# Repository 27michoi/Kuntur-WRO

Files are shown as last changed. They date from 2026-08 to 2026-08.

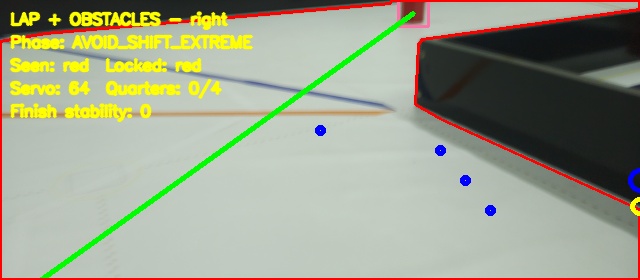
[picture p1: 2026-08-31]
step13_lap_results/frames/right_20260828_172251/frame_0032_AVOID_SHIFT_EXTREME.jpg

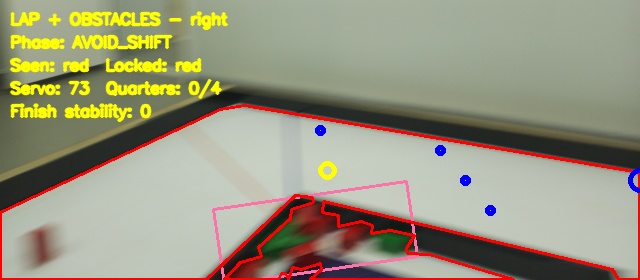
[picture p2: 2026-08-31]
step13_lap_results/frames/right_20260828_172251/frame_0070_AVOID_SHIFT.jpg

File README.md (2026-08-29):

## Introducción

Nuestro equipo Kuntur creó «Luna» para participar en el Campeonato Nacional de la WRO 2026 (Lima, Perú). «Luna» es un carro de conducción autónoma, diseñado para detectar obstáculos y analizar su entorno con el fin de adaptar su conducción de forma adecuada. Colocamos la Raspberry Pi 3 Wide en la parte superior del carro. Utilizamos un stepper motor para crear un sistema de diferencial que acciona las dos ruedas traseras y un servomotor para crear un eje para las dos ruedas delanteras. Programamos nuestra cámara para que detectara líneas específicas, objetos de colores distintivos y las paredes.

**Por favor, lee los archivos README.md en cada carpeta para comprender mejor nuestra documentación.**

---

### Visión General y Filosofía del Proyecto

El desarrollo de «Luna» representa la culminación de un proceso intensivo de ingeniería mecatrónica, diseño de software y resolución de problemas por parte del Equipo Kuntur. Diseñar un vehículo verdaderamente autónomo capaz de desenvolverse de manera fluida y precisa dentro de un tapete delimitado de 3x3 metros exige una integración armónica entre el hardware mecatrónico y los algoritmos de decisión en tiempo real.

La navegación en un espacio acotado presenta desafíos únicos. El espacio limitado requiere que las maniobras de esquiva, corrección de trayectoria y detección de límites se ejecuten con una latencia mínima. A diferencia de plataformas más grandes o que operan en entornos abiertos, «Luna» no cuenta con margen de error para desviaciones acumulativas. Una pequeña imprecisión en la lectura de la línea de carril o un retardo en la señal del servo puede traducirse en una colisión contra una pared o la desalineación irreversible del vehículo dentro del circuito. Por esta razón, el Equipo Kuntur adoptó un enfoque metodológico estricto: cada decisión de diseño, desde la selección de materiales hasta la estructura de las clases en el código fuente, se orientó hacia la estabilidad, la repetibilidad y el control de precisión.

El nombre «Luna» simboliza la exploración y la guía en entornos desafiantes, reflejando el espíritu competitivo y la dedicación del equipo durante las etapas de conceptualización, prototipado y pruebas finales para el Campeonato Nacional de la WRO 2026.

---

### Arquitectura de Hardware y Diseño Mecánico

El chasis de «Luna» se diseñó bajo el principio de rigidez estructural y modularidad. Para lograr un vehículo liviano pero resistente a las variaciones dinámicas de masa durante la aceleración y el viraje, combinamos componentes fabricados mediante impresión 3D en PLA con elementos estructurales de LEGO Technic.

#### Chasis Híbrido y Modularidad

La base estructural del carro se divide en tres secciones claramente diferenciadas:

1. **Módulo Delantero de Dirección:** Alberga el servomotor y el varillaje mecánico que conecta los manguetones de las ruedas delanteras. Se diseñó específicamente para permitir un ajuste de alineación rápido y garantizar que el eje de rotación de cada rueda respete la geometría de giro sin generar tensiones en los brazos mecánicos.
2. **Cuna Central de Electrónica:** Posicionada estratégicamente en el centro de gravedad del vehículo. En esta zona se fijan la Raspberry Pi 3 Wide, el microcontrolador de bajo nivel, los convertidores de voltaje y los circuitos de distribución de energía. Al concentrar el peso electrónico en el centro, se reduce el momento de inercia del vehículo, permitiendo giros más ágiles y predecibles.
3. **Módulo Trasero de Propulsión:** Contiene el motor paso a paso (stepper motor), el tren de engranajes reductor y el mecanismo diferencial que transmite el movimiento a las ruedas traseras.

La integración de piezas de LEGO Technic en las vigas longitudinales permitió iterar con rapidez la posición exacta de los componentes durante las fases iniciales de prueba. Posteriormente, los soportes definitivos para la cámara, los sensores y las placas electrónicas se modelaron en CAD y se imprimieron en 3D, garantizando un acoplamiento perfecto mediante tornillería estandarizada. Los archivos de estos diseños están disponibles en la carpeta `models`.

#### Sistema de Tracción Posterior por Motor Paso a Paso Único

Una de las decisiones técnicas más representativas en el diseño de «Luna» fue la utilización de un único motor paso a paso para mover ambas ruedas traseras. En lugar de recurrir a la clásica configuración de dos motores de corriente continua independientes con control diferencial por software, optamos por un esquema mecánico basado en un diferencial físico impulsado por el motor paso a paso.

Esta configuración ofrece ventajas decisivas:

* **Control de Odometría Absoluta:** Un motor paso a paso avanza en incrementos angulares exactos y discretos. Al conocer la relación de transmisión de los engranajes y el radio de las ruedas, el software puede determinar con extrema precisión la distancia lineal recorrida contando simplemente la cantidad de pulsos enviados al motor. Esto elimina la necesidad de instalar codificadores ópticos o magnéticos externos en los ejes de las ruedas.
* **Eliminación de Desviaciones por Diferencia de Motores:** En sistemas con dos motores de corriente continua, pequeñas variaciones en la resistencia interna de los motores o en la fricción de los rodamientos causan que una rueda gire ligeramente más rápido que la otra, desviando al vehículo de su trayectoria recta. Al usar un solo motor paso a paso unido a un diferencial mecánico, ambas ruedas reciben la misma fuerza motriz, garantizando un avance perfectamente rectilíneo cuando la dirección se mantiene en el centro.
* **Diferencial Mecánico Activo:** Al tomar curvas cerradas dentro del tapete de 3x3 metros, la rueda trasera interior recorre una distancia menor que la rueda exterior. El diferencial mecánico permite esta diferencia de velocidad angular entre las ruedas sin perder la tracción del motor, evitando que los neumáticos derrapen o arrastren sobre la superficie del tapete.

#### Sistema de Dirección Delantera

La dirección de «Luna» se confía a un servomotor de alta precisión conectado a las ruedas delanteras mediante un varillaje articulado.

* **Geometría de Dirección:** El mecanismo se diseñó para aproximar la geometría de giro Ackermann, asegurando que la rueda interior mantenga un ángulo ligeramente superior a la rueda exterior durante un viraje. Esto reduce la fricción lateral del neumático delantero y proporciona un control de trayectoria suave.
* **Calibración y Protección Mecánica:** A través de rutinas de calibración específicas, fijamos el ángulo de centro mecánico en el software y definimos bordes de seguridad rígidos. Estos límites previenen que el servomotor intente girar más allá del tope físico de la suspensión, evitando sobrecalentamientos, consumo excesivo de batería o daños en los engranajes del servo.

---

### Esquema Electrónico y Distribución de Alimentación

El correcto diseño del sistema eléctrico es crucial para prevenir fallas aleatorias, caídas de voltaje o ruido electromagnético que pueda interferir con el procesamiento de la Raspberry Pi o la lectura de señales. Los esquemas electromecánicos completos se encuentran en la carpeta `schemes`.

#### Sistema de Procesamiento Jerárquico

Para optimizar el rendimiento y garantizar tiempos de respuesta en tiempo real, dividimos las tareas computacionales en dos niveles jerárquicos:

* **Procesador de Alto Nivel (Raspberry Pi 3 Wide):** Actúa como el "cerebro" del robot. Ejecuta el sistema operativo Linux, la pila de visión por computador en Python mediante la librería OpenCV, la lógica de navegación general, la detección de colores y obstáculos, y la toma de decisiones tácticas.
* **Controlador de Bajo Nivel (Microcontrolador Arduino):** Actúa como el "sistema nervioso" del robot. Se encarga exclusivamente de generar las señales físicas en tiempo real: los pulsos de alta frecuencia para el driver del motor paso a paso y la señal de modulación por ancho de pulsos (PWM) para el servomotor de la dirección.

Esta separación garantiza que las tareas críticas de tiempo como la generación de pasos del motor no sufran interrupciones ni fluctuaciones debido a la carga de procesamiento de la cámara en la Raspberry Pi.

#### Red de Alimentación y Aislamiento Electrónico

El sistema eléctrico de «Luna» se alimentó mediante un esquema de distribución cuidadosamente aislado:

* **Línea de Potencia (Motores y Servo):** Alimenta los actuadores mecánicos a través de un controlador dedicado (driver) para el motor paso a paso y una línea de regulador de voltaje de alta corriente para el servomotor. Esto aísla los picos de corriente que ocurren durante los arranques o detenciones bruscas del motor.
* **Línea de Lógica (Raspberry Pi y Sensores):** Cuenta con una regulación de voltaje filtrada que proporciona un suministro de energía limpio a la Raspberry Pi 3 Wide y al microcontrolador.
* **Masa Común y Filtrado:** Todas las líneas de masa del sistema se unieron en un punto común para establecer una referencia de voltaje idéntica en toda la electrónica. Se incorporaron condensadores de desacoplo de gran capacidad cerca de los controladores de motor para absorber los transitorios de inductancia.

---

### Sistema de Visión por Computador y Navegación Autónomica

El único sensor primario de percepción del entorno en «Luna» es la cámara Raspberry Pi 3 Wide colocada en la parte superior del chasis. Elegimos una lente de gran angular para maximizar el campo de visión, permitiendo que el robot observe simultáneamente el suelo inmediatamente delante de su paragolpes y las paredes o límites laterales del tapete.

#### Procesamiento de Imágenes en el Espacio de Color HSV

Las variaciones en la iluminación ambiental dentro del recinto de la competencia pueden alterar severamente la percepción del color si se trabaja en el espacio RGB convencional. Por ello, la primera etapa de nuestra canalización de visión convierte los fotogramas capturados por la cámara al espacio de color HSV (Hue, Saturation, Value):

1. **Canal Tono (Hue):** Representa el color puro de manera independiente de la intensidad luminosa. Esto permite definir rangos de umbración estables para aislar colores clave como el rojo, el verde, el azul y el negro de las líneas o paredes.
2. **Canales Saturación (Saturation) y Valor (Value):** Se utilizan para filtrar reflejos del suelo o zonas de sombra demasiado oscuras, asegurando que solo se procesen regiones con suficiente pureza de color.

#### Algoritmo de Detección de Paredes y Centrado de Carril

Para mantener a «Luna» en el centro del carril dentro del tapete de 3x3 metros, implementamos un algoritmo de análisis de contornos en la Región de Interés (ROI) de la imagen:

* **Definición de ROI:** Se descarta la parte superior de la imagen (que contiene elementos del entorno fuera del tapete) y se enfoca el procesamiento en la franja central e inferior del fotograma.
* **Segmentación de Límites:** Se aplican filtros morfológicos de erosión y dilatación para eliminar el ruido puntual. A continuación, se extraen los contornos de las paredes o líneas delimitadoras izquierda y derecha.
* **Cálculo del Punto Medio:** El software calcula el centroide espacial de los contornos detectados a ambos lados. La diferencia entre el centroide combinado de la pista y el centro geométrico del fotograma genera un vector de error. Este vector de error se convierte directamente en el ángulo de corrección para el servomotor de la dirección mediante una función de transferencia proporcional.

#### Detección y Evitación de Obstáculos

Además de seguir las paredes y líneas del circuito, «Luna» debe ser capaz de reaccionar ante obstáculos colocados en su trayectoria:

* **Evaluación de Área y Distancia:** Cuando el módulo de visión detecta una masa de color correspondiente a un objeto dentro de la ROI, calcula el área en píxeles del contorno. Si el área supera un umbral predefinido, el sistema determina que el objeto está a una distancia crítica de colisión.
* **Lógica de Esquiva por Código de Color:** Dependiendo del color del objeto identificado (por ejemplo, verde para esquivar por un costado o rojo para el lado opuesto), el algoritmo de decisión invalida temporalmente la referencia de centrado de paredes e introduce un desvío angular forzado en la dirección. Una vez que el contorno del objeto sale del campo de visión lateral de la cámara, el sistema retorna suavemente al modo de seguimiento de carril.

---

### Estructura del Software y Flujo de Control (`src`)

Todo el software desarrollado para controlar a «Luna» se encuentra documentado y estructurado modularmente dentro de la carpeta `src`. La arquitectura sigue patrones de diseño orientados a objetos en Python, asegurando un código limpio, reutilizable y fácil de depurar.

#### Arquitectura de Clases

* `run.py`: Script de entrada principal. Inicializa las clases de comunicación, la captura de video en un hilo dedicado, procesa el bucle principal de control y gestiona las paradas de emergencia.
* `classes/arduino_comms.py`: Encargada de gestionar la conexión serie (`/dev/ttyACM0` a 115200 baudios). Incluye funciones para empaquetar y enviar comandos de movimiento y leer las respuestas enviadas por el Arduino.
* `classes/image_algorithms.py`: Contiene los métodos matemáticos de visión por computador, la segmentación HSV, la detección de contornos, el cálculo de centroides y la generación de órdenes angulares.
* `battery.py`: Script de diagnóstico que evalúa la tensión del sistema antes de cada sesión de pruebas.

#### Protocolo de Comunicación Serie y Trama de Datos

La comunicación entre la Raspberry Pi y el Arduino se rige por un protocolo ligero basado en cadenas ASCII:

* **Comandos de Dirección y Velocidad:** Formateados como `m<ángulo>,<velocidad>.` (por ejemplo, `m85,1000.` indica fijar el servo en el centro de 85 grados y mover el motor paso a paso a 1000 pasos por segundo).
* **Comandos de Odometría Objetivo:** Formateados como `<pasos>!` (por ejemplo, `5000!` le indica al microcontrolador que debe avanzar exactamente 5000 pasos y detenerse).
* **Señales de Confirmación:** Cuando el microcontrolador completa una orden de pasos objetivo, transmite el carácter `'F'` por el puerto serie. La clase `ArduinoComms` intercepta este carácter para notificar al software principal que la maniobra ha concluido con éxito.

---

### Metodología de Calibración y Procedimiento Paso a Paso

Para garantizar que el vehículo funcione de forma idéntica en cada ejecución, establecimos un protocolo de calibración estructurado en 6 pasos que debe ejecutarse secuencialmente antes de cada competición o sesión de pruebas dinámicas.

```
+-----------------------------------------------------------------------+
|  Paso 1: Diagnóstico Electrónico y Nivel de Carga (battery.py)         |
+-----------------------------------+-----------------------------------+
                                    |
                                    v
+-----------------------------------------------------------------------+
|  Paso 2: Verificación de la Interfaz Serie (ArduinoComms)             |
+-----------------------------------+-----------------------------------+
                                    |
                                    v
+-----------------------------------------------------------------------+
|  Paso 3: Calibración de la Cámara y Umbralización HSV                 |
+-----------------------------------+-----------------------------------+
                                    |
                                    v
+-----------------------------------------------------------------------+
|  Paso 4: Calibración de Centro de Servo y Límites de Seguridad        |
+-----------------------------------+-----------------------------------+
                                    |
                                    v
+-----------------------------------------------------------------------+
|  Paso 5: Prueba de Avance / Parada Objetivo con Ruedas Elevadas       |
+-----------------------------------+-----------------------------------+
                                    |
                                    v
+-----------------------------------------------------------------------+
|  Paso 6: Pruebas Dinámicas en Pista y Ajuste de Bucle Cerrado         |
+-----------------------------------------------------------------------+

```

#### Paso 1: Diagnóstico Electrónico y Nivel de Carga

Antes de activar los motores, se ejecuta el script de diagnóstico de batería. Esto confirma que el voltaje de las líneas de lógica y potencia se encuentre dentro del rango nominal, evitando que caídas de tensión provoquen comportamientos anómalos en el motor paso a paso o en el procesamiento de la imagen.

#### Paso 2: Verificación de la Interfaz Serie

Se valida que el puerto USB serie entre la Raspberry Pi y el Arduino se abra correctamente a 115200 baudios, enviando tramas de prueba para medir la latencia del canal de comunicación y confirmar que no existan paquetes corruptos en el búfer.

#### Paso 3: Calibración de la Cámara y Umbralización HSV

Dado que la luz ambiente del recinto de la competición varía según la hora y la iluminación de la sala, colocamos al robot en diferentes puntos del tapete para ajustar los valores mínimos y máximos de los canales HSV. Guardamos estos parámetros en los archivos de configuración para garantizar una segmentación de color precisa.

#### Paso 4: Calibración de Centro de Servo y Límites de Seguridad

Se eleva el eje delantero para eliminar la fricción con el suelo. Mediante una consola interactiva, ajustamos el valor de `ANGLE_STRAIGHT` hasta que las ruedas delanteras queden perfectamente alineadas con el chasis (fijado nominalmente en 85 grados). Posteriormente, probamos los giros máximos a izquierda y derecha para establecer límites estrictos en el software que prevengan bloqueos mecánicos.

#### Paso 5: Prueba de Avance y Parada Objetivo con Ruedas Elevadas

Con el vehículo aún suspendido sobre un soporte, probamos el sistema de tracción posterior:

1. **Verificación de Dirección de Marcha:** Confirmamos que los comandos de velocidad positiva hagan girar ambas ruedas traseras en sentido de avance hacia adelante a través del diferencial.
2. **Respuesta a la Parada Objetivo:** Enviamos un comando de 5000 pasos y verificamos que el motor paso a paso se detenga automáticamente al alcanzar la cuenta exacta, transmitiendo la señal de confirmación `'F'` de regreso a la Raspberry Pi.

#### Paso 6: Pruebas Dinámicas en Pista y Ajuste de Bucle Cerrado

Finalmente, colocamos a «Luna» sobre el tapete de 3x3 metros. Ejecutamos el bucle de control completo en `run.py`, ajustando las ganancias de respuesta del algoritmo de dirección para lograr un seguimiento de carril fluido, sin sobreoscilaciones en las curvas y con una esquiva de obstáculos limpia y predecible.

---

### Organización de Repositorio y Documentación

Para garantizar que cualquier miembro de la comunidad de la WRO o jurado de la competencia pueda revisar, replicar o continuar nuestro trabajo, organizamos el repositorio oficial del Equipo Kuntur respetando una estructura estricta de carpetas. Cada directorio cuenta con su respectivo archivo `README.md` explicativo:

* **`t-photos/`**: Contiene la documentación fotográfica del equipo Kuntur. Incluye una foto oficial para la presentación de la competencia y una foto informal que refleja el espíritu colaborativo del grupo.
* **`v-photos/`**: Agrupa 6 fotografías detalladas de «Luna» desde todos los ángulos clave: vista superior (mostrando la disposición de la Raspberry Pi y el cableado), vista inferior (revelando el tren de engranajes del diferencial y el soporte del motor paso a paso), así como vistas frontal, posterior y laterales.
* **`video/`**: Contiene el archivo `video.md`, el cual proporciona el enlace directo al video demostrativo alojado en línea, donde se aprecia a «Luna» ejecutando una prueba completa de conducción autónoma en el tapete de 3x3 metros.
* **`schemes/`**: Alberga los esquemas mecánicos y electrónicos en formato JPEG, detallando la interconexión entre la Raspberry Pi, el Arduino, el driver del stepper motor, el servomotor y la red de alimentación.
* **`src/`**: Guarda la totalidad del código fuente ejecutable, incluyendo las clases de comunicación, los algoritmos de visión, los scripts de prueba individuales y el ejecutable principal `run.py`.
* **`models/`**: Contiene los archivos CAD en formato STL y código G para la impresión 3D de los componentes del chasis y soportes de sensores.
* **`other/`**: Reúne documentación complementaria, como hojas de datos técnicas de los componentes utilizados, bitácoras de pruebas de campo y archivos de configuración auxiliares.

---

### Resultados, Conclusiones y Agradecimientos

El desarrollo de «Luna» ha sido una experiencia de aprendizaje técnico inestimable para todo el Equipo Kuntur. A través de este proyecto logramos validar de manera práctica conceptos avanzados de mecatrónica, ingeniería de software, visión por computador y control en tiempo real.

El uso de un motor paso a paso acoplado a un diferencial mecánico demostró ser una alternativa innovadora y altamente eficiente para la tracción trasera de vehículos autónomos a pequeña escala, ofreciendo una odometría exacta sin incrementar la complejidad de sensores en el chasis. Del mismo modo, la arquitectura de procesamiento dual entre la Raspberry Pi 3 Wide y el Arduino garantizó un equilibrio perfecto entre capacidad de cómputo visual y precisión en la generación de señales de control.

Agradecemos sinceramente al Campeonato Nacional de la WRO 2026 en Lima, Perú, por brindar la oportunidad de poner a prueba nuestras capacidades de ingeniería, así como a nuestros mentores y familias por su apoyo constante durante las largas jornadas de diseño, impresión 3D y programación. Invitamos a todos los visitantes de nuestro sitio web a explorar las diferentes carpetas de nuestro repositorio para conocer a fondo los detalles técnicos que hacen de «Luna» un vehículo autónomo único.

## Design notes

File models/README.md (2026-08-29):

# 3D Models
____

## Resumen

Este directorio contiene los archivos STL de los componentes impresos en 3D de nuestro robot para la WRO 2026. Los modelos incluyen las piezas del chasis estructural, del mecanismo de dirección, de los soportes de los motores, del soporte de la cámara y otros componentes mecánicos utilizados en el vehículo.
También se incluye una descripción del armado del robot junto con indicaciones para el ensamblaje.

____

## Estructura del chasis

### Placas de base

[`BasePlaqueV4.stl`](./BasePlaqueV4.stl)
[`BasePlaqueV4-modifiedV1.stl`](./BasePlaqueV4-modifiedV1.stl) 

### Placas del medio

[`MiddlePlaqueV4.stl`](./MiddlePlaqueV4.stl)
[`MiddlePlaqueV4-modified_lu.stl`](./MiddlePlaqueV4-modified_lu.stl)

### Placas superiores

[`TopPlaqueV4.stl`](./TopPlaqueV4.stl)

____

## Sistema de conducción

### Componentes de dirección

[`DirectionRods3.stl`](./DirectionRods3.stl)
[`DirectionRodsShort3.stl`](./DirectionRodsShort3.stl)
[`DirectionTabsLH.stl`](./DirectionTabsLH.stl)
[`DirectionTabsRH.stl`](./DirectionTabsRH.stl)

### Componentes de servo

[`ServoHolderV2.stl`](./ServoHolderV2.stl)
[`ServoCover.stl`](./ServoCover.stl)

____

## Sistema de manejo

[`StepMotorBracker.stl`](./StepMotorBracket.stl)
[`BaseMotorBig.stl`](./BaseMotorBig.stl)
[`CouplingV3.stl`](./CouplingV3.stl)

____

## Sistema de cámara

[`CamHolderV4.stl`](./CamHolderV4.stl)

____

## Componentes externos y auxiliares

[`FrontWingV2.stl`](./FrontWingV2.stl)
[`ButtonHolder.stl`](./ButtonHolder.stl)

___

# Diseño Mecánico

## Descripción general

Esta carpeta contiene los archivos correspondientes al diseño mecánico del robot autónomo desarrollado para la competencia WRO Future Engineers.

El diseño mecánico tuvo como objetivo principal desarrollar una estructura resistente, modular y fácil de ensamblar, permitiendo realizar modificaciones rápidas durante la etapa de pruebas y preparación para la competencia.

Los principales criterios de diseño fueron:

- Lograr una estructura rígida y estable para soportar todos los componentes mecánicos y electrónicos.
- Permitir un montaje y desmontaje sencillo de las piezas.
- Facilitar el mantenimiento y reemplazo de componentes durante las pruebas.
- Mejorar la precisión del sistema de dirección y transmisión.

Las piezas personalizadas fueron diseñadas mediante software CAD y fabricadas mediante impresión 3D.

---

# Arquitectura del chasis

El robot está compuesto por una estructura modular de tres niveles principales:

1. Placa inferior del chasis.
2. Placa intermedia para componentes electrónicos.
3. Placa superior para Raspberry Pi y sistema de cámara.

Las placas están unidas mediante pernos y separadores previamente calculados, permitiendo mantener una distancia adecuada entre niveles para organizar los componentes internos y evitar interferencias mecánicas.

---

# Placa inferior del chasis

La placa inferior constituye la base principal del robot.

En esta sección se encuentran instalados:

- Cuatro ruedas alineadas.
- Sistema de transmisión mediante motor paso a paso.
- Sistema diferencial de engranajes.
- Sistema de dirección Ackermann.
- Servomotor de dirección.
- Soporte para convertidor de voltaje DC-DC.

El diseño fue desarrollado para mantener una distribución equilibrada de peso y garantizar estabilidad durante el movimiento autónomo.

---

# Sistema de transmisión

## Motor y diferencial

El sistema de movimiento utiliza:

- Motor paso a paso NEMA 17.
- Engranaje diferencial bevel de 28 dientes.
- Eje de transmisión hacia las ruedas posteriores.

El motor transmite el movimiento mediante el sistema diferencial, permitiendo que las ruedas puedan adaptarse a diferentes velocidades durante los giros.

Este mecanismo reduce esfuerzos mecánicos y mejora la estabilidad del vehículo en curvas.

El soporte del motor fue diseñado para mantener una correcta alineación entre los engranajes y evitar pérdidas por desajustes mecánicos.

---

# Sistema de dirección Ackermann

El robot utiliza una geometría Ackermann para mejorar el comportamiento durante los giros.

El sistema está compuesto por:

- Soportes de ruedas delanteras.
- Elementos de unión de dirección.
- Ejes de giro.
- Servomotor.
- Sistema de conexión mecánica.

Durante las primeras pruebas se identificó que las piezas impresas en 3D presentaban cierta resistencia debido al contacto directo entre superficies plásticas.

Esto generaba:

- Mayor fricción.
- Menor precisión del movimiento.
- Mayor esfuerzo del servomotor.
- Variaciones en el ángulo de giro.

Para solucionar este problema se rediseñaron los soportes incorporando rodamientos de acero en los puntos de rotación.

La implementación de rodamientos permitió:

- Reducir la resistencia mecánica.
- Mejorar la suavidad del movimiento.
- Aumentar la precisión del control del servomotor.
- Obtener una respuesta más estable del sistema Ackermann.

---

# Placa intermedia de componentes electrónicos

La placa intermedia fue diseñada para organizar y proteger los componentes eléctricos del robot.

En ella se montan:

- Arduino Uno R3 Microcontroller.
- Mini protoboard.
- Baterías recicladas 18650 (4 celdas).
- Convertidor DC-DC de 12V a 5V (6A - 30W).
- Distribución del cableado.

La separación entre la placa inferior y la placa intermedia fue definida mediante separadores, considerando:

- Espacio necesario para cables.
- Facilidad de mantenimiento.
- Protección de componentes.
- Evitar contacto entre sistemas mecánicos y eléctricos.

---

# Sistema de alimentación

El robot utiliza un conjunto de cuatro baterías recicladas 18650.

La ubicación del sistema de baterías fue definida buscando:

- Mantener el centro de gravedad equilibrado.
- Evitar desplazamientos de peso durante aceleraciones.
- Mejorar la estabilidad del vehículo.

El convertidor DC-DC permite adaptar la tensión del sistema de baterías a los niveles requeridos por los componentes electrónicos.

---

# Placa superior y sistema de visión

La placa superior permite cerrar la estructura del robot y proporciona soporte para:

- Raspberry Pi 5 Starter Kit.
- Cámara Raspberry Pi.

El soporte de cámara fue diseñado para mantener una posición fija respecto al chasis.

Su ubicación permite realizar una correcta calibración considerando:

- Distancia hacia obstáculos.
- Altura de visión.
- Reconocimiento de elementos de la pista.

Una posición estable de la cámara permite mejorar la repetibilidad del sistema autónomo durante las pruebas.

---

# Procedimiento de ensamblaje

## 1. Ensamblaje del chasis inferior

1. Instalar el motor NEMA 17 en su soporte.
2. Colocar el sistema diferencial de engranajes.
3. Verificar alineación del eje de transmisión.
4. Instalar las ruedas posteriores.
5. Montar el sistema Ackermann delantero.
6. Instalar los rodamientos en los puntos de giro.
7. Conectar el servomotor al sistema de dirección.

---

## 2. Instalación de placa intermedia

1. Colocar los separadores entre placas.
2. Fijar la placa intermedia mediante pernos.
3. Instalar Arduino Uno.
4. Colocar baterías y convertidor DC-DC.
5. Organizar conexiones eléctricas.

---

## 3. Instalación de placa superior

1. Fijar la placa superior al conjunto.
2. Instalar Raspberry Pi 5.
3. Colocar soporte de cámara.
4. Ajustar posición de cámara según las necesidades de calibración.

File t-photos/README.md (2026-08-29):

## Fotos del equipo

Este directorio contiene dos fotos del equipo (una oficial y otra divertida en la que aparecen todos los miembros del equipo).

Aunque nuestros nombres son Camilla, Luciana y Minjun (izquierda a derecha en las fotos), nuestras identidades en la foto divertida son Raspi, Arduino y protoboard!

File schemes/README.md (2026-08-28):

Electromechanical diagrams
====

___

## Introducción

Este directorio documenta la configuración electromecánica de nuestro vehículo. Los esquemas ilustran cómo se conectan entre sí, dentro del robot, la Raspberry Pi, el Arduino, los motores, el controlador de motores y otros componentes auxiliares.

Nuestro sistema divide las responsabilidades entre dos controladores principales. La Raspberry Pi 5 actúa como nuestra computadora principal, procesando la información procedente del módulo de cámara Raspberry Pi Camera Module 3 Wide y ejecutando las pruebas integradas que se utilizan para evaluar el rendimiento general del robot. El Arduino Uno se encarga de los mecanismos de movimiento del vehículo, comunicándose con los sistemas de dirección y conducción.

Los diagramas representan tanto la configuración completa del vehículo como una configuración de prueba centrada en el chasis.

____

## Configuración del Sistema

El sistema electromecánico de nuestro robot puede entenderse a través de cuatro funciones principales.

1. **Visión y cálculo**: a cargo de la Raspberry Pi 5 y el módulo de cámara Raspberry Pi 3 Wide.
2. **Dirección**: controlada mediante el Arduino, el servomotor y el mecanismo de dirección de las ruedas delanteras.
3. **Propulsión**: controlada mediante el Arduino, el controlador del stepper motor driver y el stepper motor.
4. **Poder**:  cuatro baterías de 3,7 V y canalizada a través del sistema de gestión de energía del vehículo.

La separación de estas funciones permite que la Raspberry Pi se centre en el procesamiento de las imágenes de la cámara y en las pruebas de nivel superior, mientras que el Arduino gestiona el hardware responsable del movimiento físico del vehículo.

____

## Configuración Completa del Vehículo

### Raspberry Pi 5 y Cámara

La Raspberry Pi 5 actúa como ordenador principal del robot, procesando los datos que recibe del módulo de cámara Raspberry Pi Camera Module 3 Wide y ejecutando nuestras pruebas de sistema completo. La cámara wide ofrece una visión más amplia del entorno de la competición.

### Arduino Uno

El Arduino Uno actúa como controlador de movimiento del vehículo, comunicándose con los sistemas de dirección y movimiento, mientras que la Raspberry Pi se encarga de la visión y del procesamiento de nivel superior.

### Servomotor (+ruedas delanteras)

El servomotor ajusta el ángulo de las ruedas delanteras para controlar la dirección del robot. La estructura de las ruedas delanteras se basa en la geometría de dirección de Ackermann.

### Stepper motor y stepper motor driver

El controlador del stepper motor driver recibe señales de control del Arduino y acciona el stepper motor, que impulsa el movimiento de las ruedas traseras del robot.

### Mini protoboard

La mini protoboard centraliza las conexiones eléctricas en un espacio compacto, lo que ayuda a mantener un esquema de cableado organizado dentro de las limitaciones de tamaño del vehículo.

### Sistema de power

El robot se alimenta mediante cuatro baterías de 3,7 V, conectadas a través de un interruptor de on/off y un convertidor DC-DC para distribuir la potencia adecuada a los componentes electrónicos.

___

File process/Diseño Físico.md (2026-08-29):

# Diario de Ingeniería - Diseño Físico del Robot Autónomo

## Inicio del proceso de diseño

El desarrollo mecánico del robot inició mediante el análisis de diferentes diseños utilizados en competencias anteriores de WRO Future Engineers, sistemas motrices encontrados en vehículos comerciales y soluciones mecánicas disponibles en plataformas como LEGO.

El objetivo inicial fue tener una arquitectura que facilitara:

- El montaje y desmontaje durante las pruebas.
- La modificación rápida de componentes.
- La accesibilidad de los sistemas internos.
- La preparación del robot para la presentación final.

Luego de evaluar diferentes alternativas, se decidió implementar una estructura modular basada en un chasis de tres niveles.

---

# Decisión del diseño modular del chasis

## Problema identificado

Un diseño de una sola placa generaba dificultades para integrar:

- Sistema de transmisión.
- Dirección.
- Baterías.
- Placas electrónicas.
- Sistema de procesamiento Raspberry Pi.
- Cámara.

Además, dificultaba realizar modificaciones rápidas durante las pruebas.

## Solución implementada

Se desarrolló un diseño compuesto por tres niveles:

### Nivel inferior:
Sistema mecánico:

- Motor.
- Diferencial.
- Ruedas.
- Dirección Ackermann.

### Nivel intermedio:
Sistema electrónico:

- Arduino.
- Baterías.
- Cableado.
- Conversor de voltaje.

### Nivel superior:
Sistema de procesamiento:

- Raspberry Pi.
- Cámara.

## Justificación

Esta separación permitió:

- Mejor organización interna.
- Mayor facilidad de mantenimiento.
- Menor interferencia entre componentes.
- Mayor rapidez para realizar ajustes.

---

# Desarrollo del sistema de transmisión

## Evaluación inicial

Se analizaron diferentes sistemas motrices utilizados en robots anteriores y vehículos comerciales.

El objetivo era encontrar una solución que proporcionara:

- Precisión de movimiento.
- Control adecuado de velocidad.
- Facilidad de integración.

## Decisión tomada

Se seleccionó:

- Motor paso a paso NEMA 17.
- Sistema diferencial mediante engranajes bevel de 28 dientes.

## Razón de la elección

El motor paso a paso permite controlar con precisión el desplazamiento del robot.

El diferencial fue seleccionado porque durante los giros las ruedas no recorren la misma distancia, por lo que permite reducir esfuerzos mecánicos y mejorar la estabilidad.

---

# Problema encontrado en el sistema Ackermann

## Primera versión

La primera versión del sistema Ackermann fue fabricada completamente mediante impresión 3D.

Durante las pruebas se observó:

- Movimiento irregular.
- Mayor resistencia mecánica.
- Pérdida de precisión del servomotor.
- Variación en el ángulo de dirección.

## Análisis del problema

La causa principal fue la fricción generada entre piezas impresas en 3D.

Debido a las características del proceso de impresión:

- Las superficies no eran completamente lisas.
- Existían pequeñas tolerancias dimensionales.
- Los puntos de giro presentaban resistencia.

Esto afectaba directamente la respuesta del sistema de dirección.

---

# Mejora mediante rodamientos

## Cambio realizado

Se rediseñaron los soportes delanteros incorporando rodamientos de acero en los puntos de giro.

## Motivo del cambio

Los rodamientos permiten reemplazar el contacto directo entre piezas plásticas por un movimiento rotacional más eficiente.

## Resultado obtenido

Después de la modificación:

- El movimiento del sistema Ackermann fue más suave.
- El servomotor requirió menor esfuerzo.
- La dirección presentó mayor precisión.
- El comportamiento durante pruebas fue más repetible.

Este diseño fue seleccionado para la versión final del robot.

---

# Diseño del sistema electrónico integrado

## Problema inicial

Durante las primeras configuraciones se identificó que los cables y componentes electrónicos podían interferir con la estructura mecánica.

Esto generaba:

- Mayor dificultad de ensamblaje.
- Riesgo de desconexiones.
- Mayor tiempo de mantenimiento.

## Solución

Se diseñó una placa intermedia específica para organizar:

- Arduino Uno.
- Protoboard.
- Baterías.
- Convertidor DC-DC.
- Cableado.

## Justificación

La placa permitió crear una estructura más limpia y modular, donde cada componente tiene una ubicación definida.

---

# Distribución de baterías y peso

Las baterías 18650 fueron ubicadas en la zona central del robot.

Esta decisión fue tomada considerando:

- Distribución uniforme de masa.
- Menor transferencia de peso durante aceleraciones.
- Mayor estabilidad en curvas.

Mantener el centro de gravedad bajo y centrado ayuda a mejorar el comportamiento del vehículo autónomo.

---

# Diseño del soporte de cámara

## Problema identificado

La precisión del sistema autónomo depende directamente de la información obtenida por la cámara.

Cambios pequeños en la posición podían modificar:

- Distancias calculadas.
- Detección de obstáculos.
- Interpretación de la pista.

## Modificación realizada

Se diseñó un soporte específico para Raspberry Pi Camera.

El soporte permite mantener:

- Altura constante.
- Ángulo fijo.
- Posición repetible.

## Resultado

La cámara pudo ser calibrada de forma consistente respecto a la pista y los obstáculos de la competencia.

---

# Diseño final seleccionado

Después de las pruebas realizadas, el diseño final integra:

- Chasis modular de tres niveles.
- Sistema diferencial con motor NEMA 17.
- Dirección Ackermann mejorada con rodamientos.
- Distribución organizada de componentes electrónicos.
- Sistema de cámara estable.

Cada modificación realizada respondió a un problema identificado durante pruebas físicas, buscando mejorar la precisión, confiabilidad y facilidad de mantenimiento del robot durante la competencia WRO Future Engineers.

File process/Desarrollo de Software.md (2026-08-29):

# Diario de Ingeniería - Desarrollo del Sistema de Programación del Robot Autónomo

## Introducción

El desarrollo del software del robot autónomo para la competencia WRO Future Engineers se realizó mediante un proceso progresivo de pruebas, validaciones y mejoras.

El objetivo principal fue construir un sistema capaz de:

- Controlar el movimiento del robot con precisión.
- Interpretar el entorno mediante visión artificial.
- Seguir la trayectoria de la pista.
- Detectar obstáculos.
- Tomar decisiones autónomas durante la competencia.

El desarrollo se dividió en diferentes etapas, comenzando desde la validación individual de componentes hasta la integración completa del sistema autónomo.

---

# Etapa inicial: Validación del movimiento y comunicación

## Objetivo

Antes de desarrollar algoritmos autónomos, fue necesario comprobar que la plataforma física respondiera correctamente.

Las primeras pruebas estuvieron enfocadas en:

- Comunicación entre Raspberry Pi y Arduino.
- Control del motor paso a paso.
- Control del servomotor.
- Determinación de velocidades seguras.
- Calibración inicial de dirección.

## Problema encontrado

El robot presentaba diferencias entre los valores enviados por software y el movimiento físico real.

Esto ocurrió debido a:

- Tolerancias mecánicas.
- Diferencias entre el ángulo indicado y el ángulo real del servo.
- Respuesta del sistema de transmisión.

## Solución aplicada

Se realizaron pruebas independientes para determinar:

- Velocidad máxima estable.
- Posición central real del servo.
- Límites seguros de giro.

Estos valores fueron utilizados posteriormente en los algoritmos autónomos.

---

# Desarrollo del sistema de cámara y visión artificial

## Primera etapa: Validación de imagen

Antes de implementar reconocimiento de objetos, se evaluó el comportamiento de la cámara en diferentes condiciones.

Se realizaron capturas considerando:

- Iluminación normal.
- Alta iluminación.
- Baja iluminación.
- Diferentes posiciones dentro de la pista.

También se analizaron:

- Paredes.
- Líneas de colores.
- Obstáculos.
- Zona de estacionamiento.

## Razón de esta etapa

La cámara es el principal sensor del robot, por lo que era necesario conocer cómo cambiaban las imágenes antes de crear algoritmos de decisión.

---

# Desarrollo del pipeline de visión

## Primera aproximación

Inicialmente se evaluó la detección directa mediante imágenes completas.

Sin embargo, este método generaba problemas debido a:

- Elementos irrelevantes dentro del campo visual.
- Variaciones de iluminación.
- Ruido en la imagen.

## Mejora implementada

Se desarrolló un pipeline de procesamiento:

1. Captura de imagen.
2. Recorte de región de interés (ROI).
3. Conversión a espacio HSV.
4. Creación de máscaras de color.
5. Limpieza mediante operaciones morfológicas.
6. Detección de contornos.
7. Obtención de centroides y dimensiones.

## Resultado

El robot pudo identificar de manera más estable:

- Líneas de pista.
- Obstáculos.
- Paredes.
- Elementos de colores utilizados en la competencia.

---

# Validación offline del sistema de visión

## Problema

Probar directamente en pista cada modificación del algoritmo consumía demasiado tiempo.

## Solución

Se creó un conjunto de imágenes de prueba obtenidas durante diferentes situaciones reales.

Estas imágenes permitieron evaluar:

- Cambios en iluminación.
- Falsos positivos.
- Capacidad de detección.

## Resultado

El sistema pudo mejorarse antes de realizar pruebas físicas, reduciendo tiempo de ajuste en pista.

---

# Desarrollo del seguimiento de paredes (Wall Following)

## Primera estrategia autónoma

Después de validar la visión, se desarrolló un método inicial basado en seguimiento de paredes.

El objetivo era que el robot pudiera mantener una distancia estable respecto al borde de la pista.

## Pruebas realizadas

Se evaluaron:

- Seguimiento por izquierda.
- Seguimiento por derecha.
- Diferentes velocidades del motor.
- Diferentes cantidades de pasos del motor.

Se realizaron pruebas con:

- 600 steps/s.
- 1660 steps.

## Problemas encontrados

El robot podía mantener la trayectoria, pero presentaba dificultades en:

- Curvas cerradas.
- Cambios bruscos de dirección.
- Interacción con obstáculos.

## Aprendizaje

El seguimiento de pared funcionaba como una base estable, pero necesitaba combinarse con detección de objetos para resolver completamente el desafío.

---

# Integración del sistema autónomo completo

## Creación de módulos de software

Para mejorar la organización del código, el programa fue dividido en módulos:

### CameraManager

Responsable de:

- Captura de imágenes.
- Configuración de cámara.
- Gestión del flujo visual.

### ImageAlgorithms

Responsable de:

- Procesamiento de imágenes.
- Detección de colores.
- Identificación de elementos.

### LapTracker

Responsable de:

- Seguimiento del progreso de vueltas.
- Identificación de etapas del recorrido.

### ContextManager

Responsable de:

- Mantener información del estado actual del robot.
- Gestionar decisiones.

### ArduinoComms

Responsable de:

- Comunicación entre Raspberry Pi y Arduino.
- Envío de comandos de movimiento.

---

# Primera versión de una vuelta completa

## Método utilizado

La pista fue dividida en cuatro secciones principales.

Cada vuelta fue interpretada como cuatro secuencias:

- Quarter-lap 1.
- Quarter-lap 2.
- Quarter-lap 3.
- Quarter-lap 4.

El robot utilizaba información visual para saber en qué etapa se encontraba.

## Parámetros calibrados

Durante estas pruebas se ajustaron:

- Servo físico central: aproximadamente 82.
- Centro lógico del programa: 86.
- Límites de dirección.
- Velocidad de movimiento: 600.

## Resultado

El robot logró completar vueltas completas de forma autónoma.

---

# Desarrollo del Challenge 2: detección y evasión de obstáculos

## Primera aproximación

Se adaptó una estrategia basada en detección de obstáculos mediante color.

El robot debía:

- Detectar obstáculos.
- Determinar el lado correcto de paso.
- Modificar trayectoria.

## Problemas encontrados

Los primeros resultados mostraron que:

- Los obstáculos podían interferir con el seguimiento de pared.
- El robot podía acercarse demasiado a elementos físicos.
- Las esquinas requerían prioridad diferente.

---

# Mejora del sistema de evasión

## Cambio realizado

Se añadió:

- Margen de seguridad alrededor del obstáculo.
- Confirmación de detección durante varios frames.
- Recuperación de trayectoria después del giro.

## Lógica implementada

El robot utiliza:

- Obstáculo verde → pasar por izquierda.
- Obstáculo rojo → pasar por derecha.

La decisión no se toma con una sola imagen, sino mediante confirmación de varios frames para reducir errores.

---

# Prioridad de paredes durante curvas

## Problema final identificado

Durante las pruebas del Challenge 2 se observó que los obstáculos cercanos a las paredes podían generar conflictos entre:

- Evitar obstáculos.
- Mantener trayectoria.

## Solución

Se modificó la lógica para dar prioridad a la protección del robot cuando existe riesgo de acercamiento excesivo a paredes.

Se incorporó:

- Margen corporal de seguridad.
- Límites de servo ajustados.
- Control de pared durante esquinas.

## Resultado

El robot logró realizar movimientos más seguros, evitando perder estabilidad por realizar maniobras demasiado agresivas.

---

# Estado final del sistema de programación

La versión final integra:

- Control de motores.
- Comunicación Raspberry Pi - Arduino.
- Procesamiento de imágenes.
- Seguimiento de pista.
- Conteo de vueltas.
- Detección de obstáculos.
- Evasión automática.
- Recuperación de trayectoria.

El desarrollo del software fue un proceso iterativo donde cada mejora surgió a partir de pruebas reales del robot.

Las decisiones finales no fueron únicamente basadas en simulación, sino en el comportamiento observado físicamente durante las pruebas en pista.

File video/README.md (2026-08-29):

Video
====

Este directorio contiene el archivo video.md con una URL de YouTube que muestra el vehículo circulando de forma autónoma.

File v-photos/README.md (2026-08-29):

## Fotos del vehículo

Este directorio contiene 6 fotos del vehículo (desde todos los ángulos, incluyendo la parte superior e inferior)

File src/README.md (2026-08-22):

Control software
====

This directory contains code for control software which is used by the vehicle to participate in the competition and which was developed by us, Kuntur.
We have documented the final codes uploaded to robot. 

Este directorio contiene el código del software de control utilizado por el vehículo para participar en la competición, desarrollado por nosotros, Kuntur.
Hemos documentado los códigos finales cargados en el robot.

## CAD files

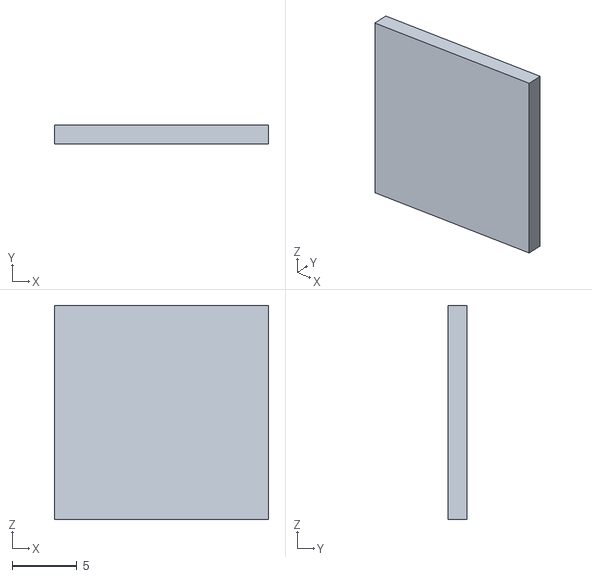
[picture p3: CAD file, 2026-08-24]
models/ServoCover.STL
16.5 x 1.50 x 16.5

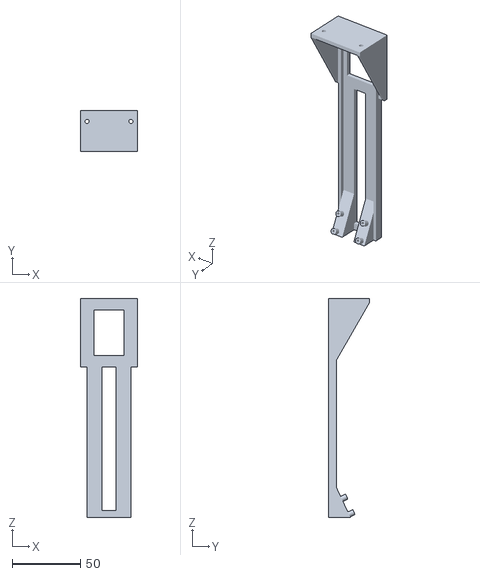
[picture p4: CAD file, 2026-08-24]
models/CamHolderV4.STL
42.0 x 30.0 x 160.0

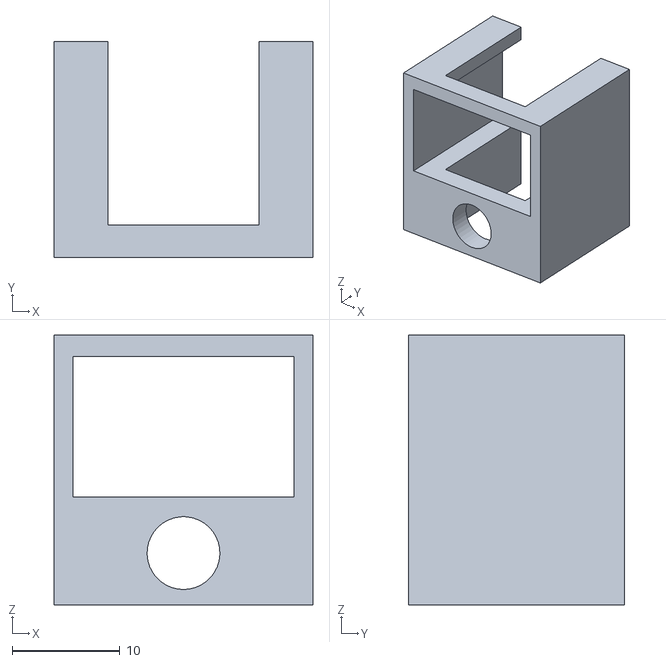
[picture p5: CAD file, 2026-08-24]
models/ButtonHolder.STL
24.0 x 20.0 x 25.0

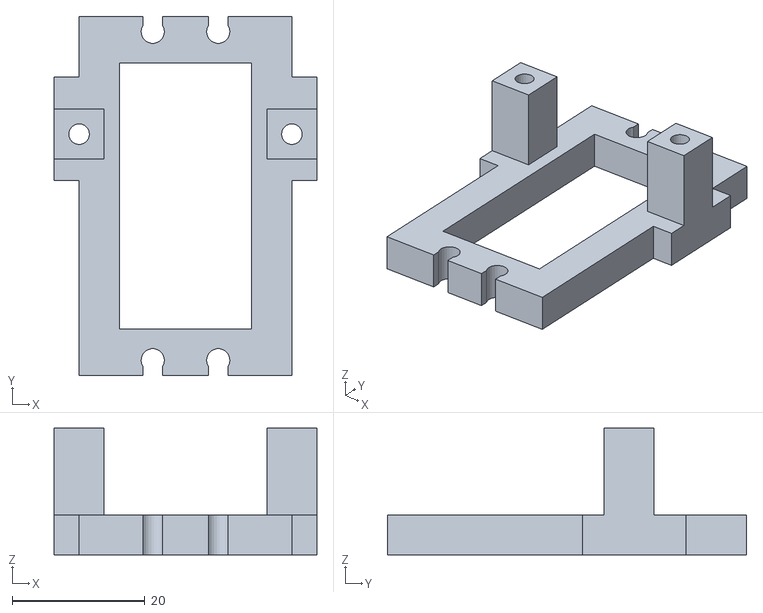
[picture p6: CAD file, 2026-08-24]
models/BaseMotorBig.stl
39.5 x 54.0 x 19.1

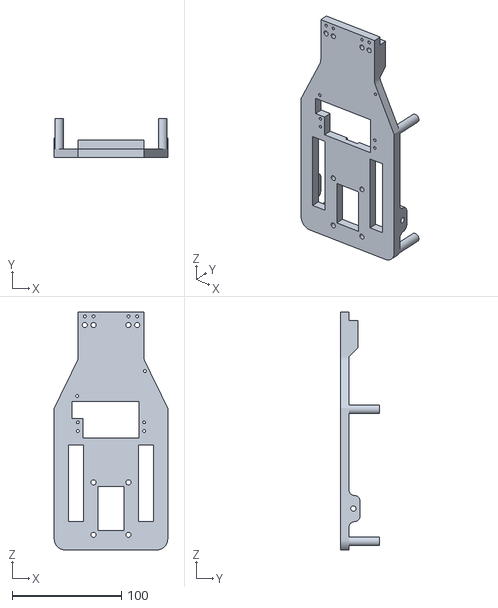
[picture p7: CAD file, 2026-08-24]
models/BasePlaqueV4.STL
104.0 x 36.0 x 218.0

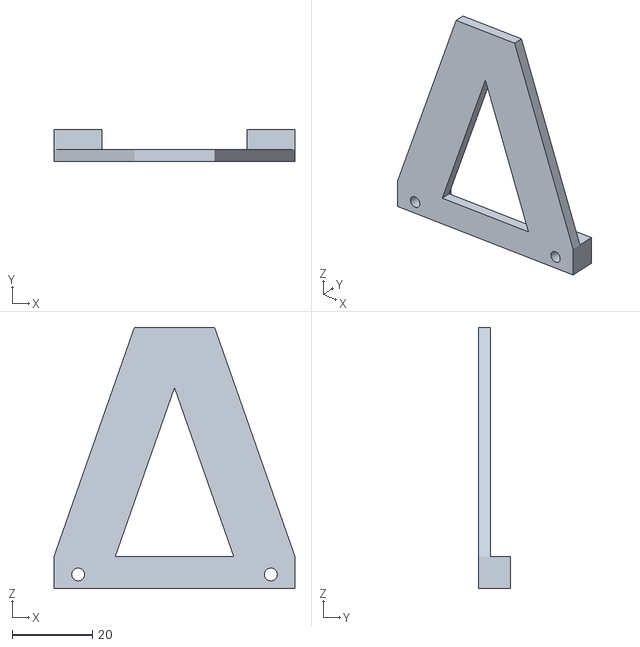
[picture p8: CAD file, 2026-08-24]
models/FrontWingV2.STL
60.0 x 8.00 x 65.0

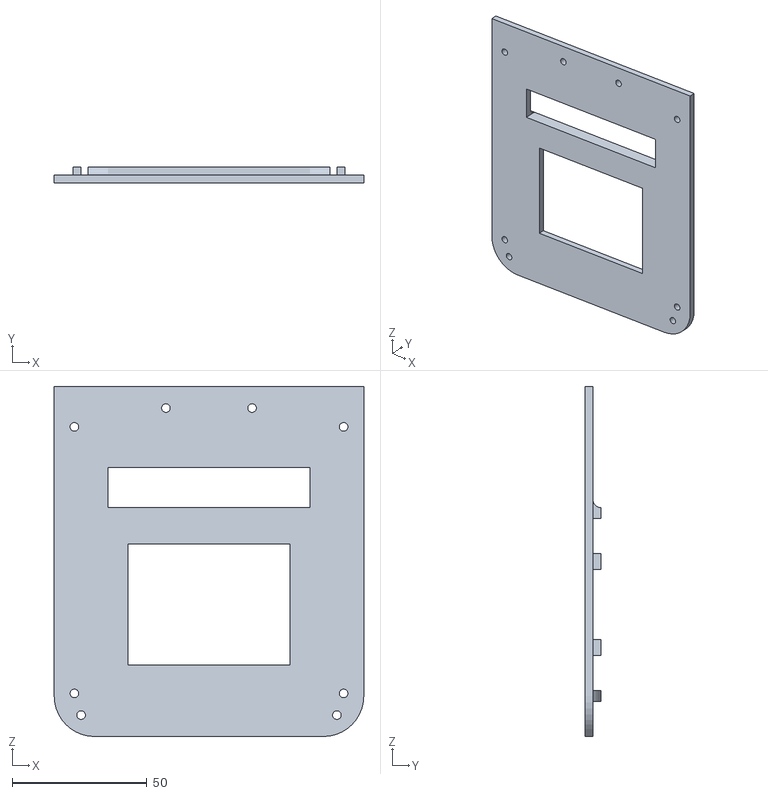
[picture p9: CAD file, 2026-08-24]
models/TopPlaqueV4.STL
115.0 x 6.00 x 130.0

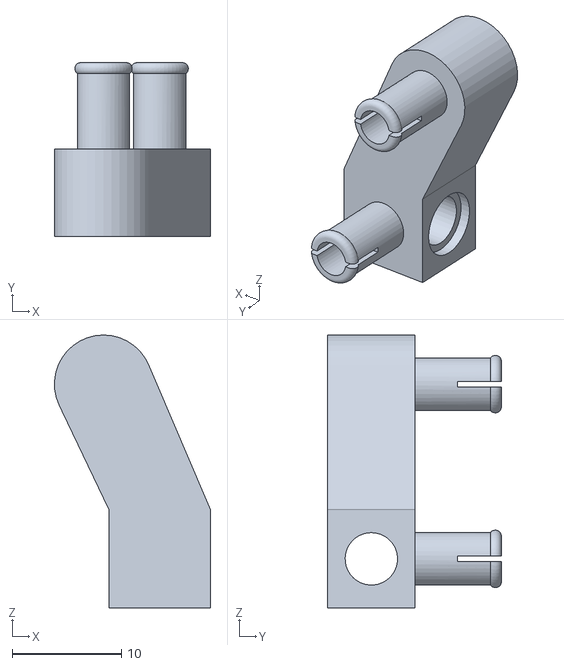
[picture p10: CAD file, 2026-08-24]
models/DirectionTabsRH.STL
14.3 x 15.9 x 25.0

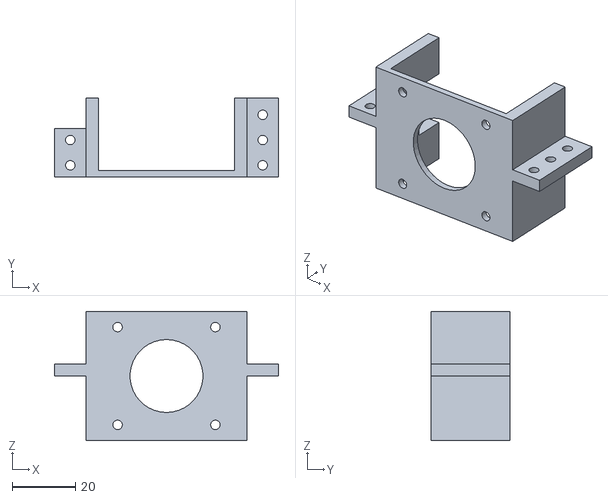
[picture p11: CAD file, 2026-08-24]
models/StepMotorBracket.STL
71.0 x 25.0 x 41.0

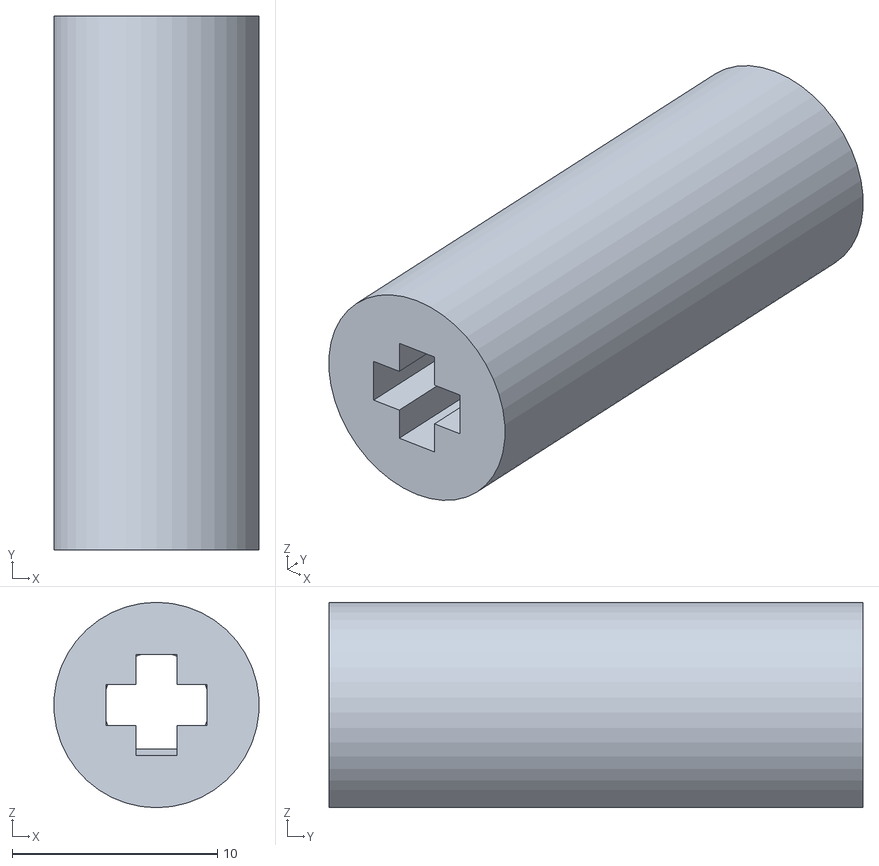
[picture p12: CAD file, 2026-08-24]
models/CouplingV3.STL
9.97 x 26.0 x 10.0

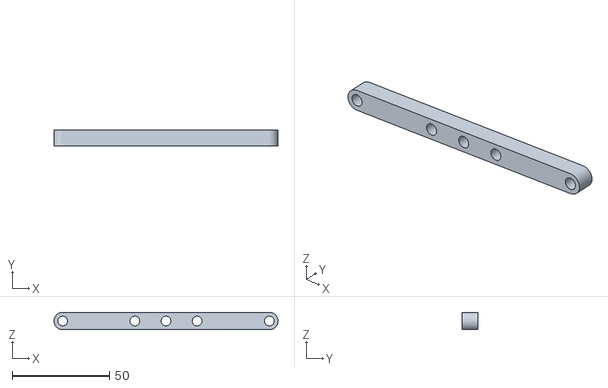
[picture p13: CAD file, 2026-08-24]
models/DirectionRods3.STL
115.3 x 8.00 x 9.00

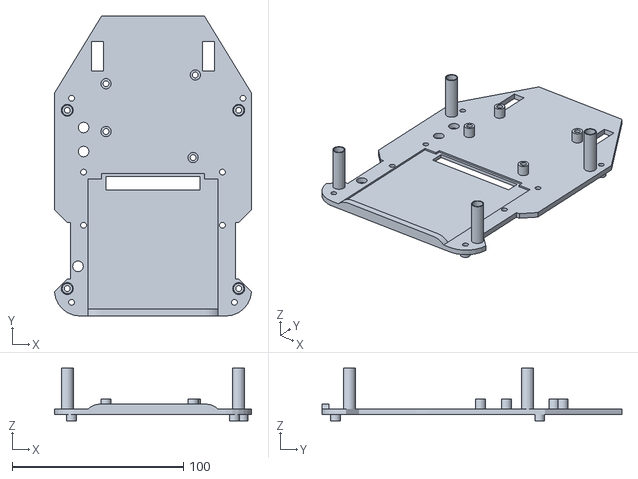
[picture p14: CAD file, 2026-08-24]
models/MiddlePlaqueV4-modified_lu.stl
115.0 x 175.0 x 30.8

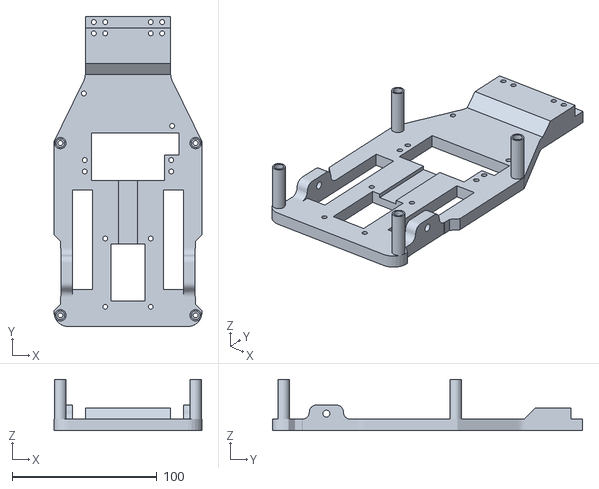
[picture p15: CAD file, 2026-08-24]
models/BasePlaqueV4-modifiedV1.stl
102.4 x 214.6 x 35.4

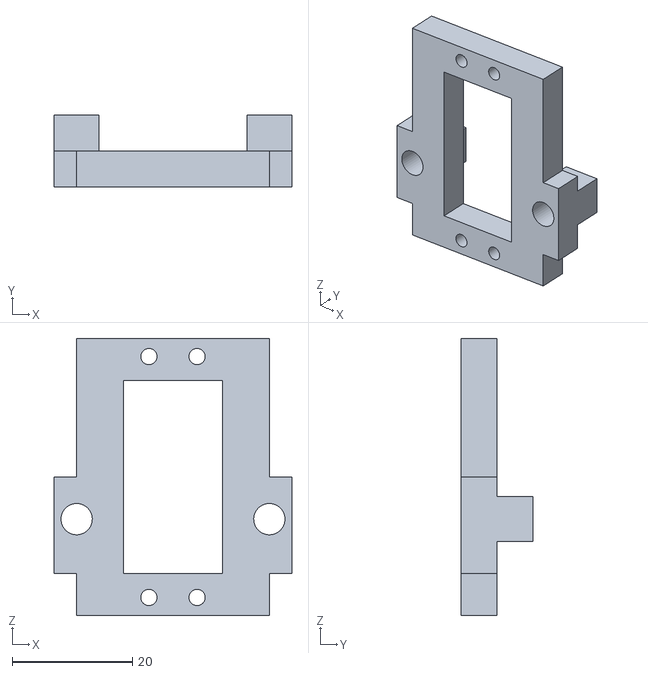
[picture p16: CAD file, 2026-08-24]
models/ServoHolderV2.STL
39.5 x 12.0 x 46.0

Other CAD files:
models/DirectionTabsLH.STL
models/DirectionRodsShort3.STL
models/MiddlePlaqueV4.STL

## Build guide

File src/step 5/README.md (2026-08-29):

Este paso verifica la dirección de tracción de los motores, el control de velocidad por comunicación serie y la función de parada precisa por distancia sin fricción en el suelo, antes de realizar pruebas de movimiento sobre la superficie.

### **Preparación y Configuración**

* **Elevación Física:** Mantenga el chasis del robot elevado de manera segura para que las ruedas motrices traseras giren libremente sin tocar ninguna superficie.
* **Ajuste del Servo:** Posicione el servomotor de dirección en el centro mecánico calibrado para mantener las ruedas delanteras alineadas.
* **Conexión Serie:** Conecte el equipo al microcontrolador a través del puerto serie USB con la velocidad de transmisión adecuada.
* **Verificación de Energía:** Verifique que la fuente de alimentación de alta corriente para los motores esté activa y compruebe el estado de las baterías de la lógica y los motores.

---

### **Flujo de Trabajo y Procedimiento de Prueba**

* **Estructura de Comandos:** Configure el sistema para enviar instrucciones de cantidad de pasos objetivo, comandos de movimiento especificando ángulo y velocidad, y la señal de confirmación de parada.
* **Fase de Giro Continuo:** Active el movimiento de avance a baja velocidad durante un periodo breve para observar la rotación de las ruedas traseras y confirmar que la dirección coincide con los valores positivos.
* **Fase de Parada por Distancia:** Inicie un recorrido especificando un número de pasos objetivo y verifique que las ruedas se detengan automáticamente al alcanzarlos, emitiendo la señal de finalización correspondiente.

---

### **Criterios de Finalización y Resolución de Problemas**

* **Validación:** Las ruedas traseras deben girar de forma fluida hacia adelante, detenerse de inmediato al recibir el comando de velocidad cero y detenerse automáticamente al alcanzar el límite de pasos establecido.
* **Manejo de Fallas:** Si las ruedas giran en sentido contrario, invierta la polaridad del cableado del motor o la lógica de control. Si no se recibe la señal de confirmación de parada, inspeccione las conexiones de los codificadores y la configuración del puerto serie.

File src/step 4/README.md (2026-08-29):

Este paso establece la línea base de calibración de la dirección, alineando las ruedas delanteras en el centro y fijando límites de seguridad para evitar atascamientos mecánicos o sobrecarga en el servomotor.

### **Preparación y Configuración**

* **Inspección Física:** Eleve el chasis del robot para que las ruedas delanteras giren libremente sin fricción con el suelo.
* **Conexión:** Verifique que el cable de señal del servo esté conectado al pin de modulación por ancho de pulsos en el microcontrolador.
* **Energía:** Asegúrese de activar las fuentes de alimentación del motor y de la lógica del sistema, comprobando los niveles de batería si es necesario.

---

### **Flujo de Trabajo de Calibración**

* **Definición de Constantes:** Revise el archivo de configuración para identificar el ángulo de centro predeterminado y registrar los rangos límites de giro hacia ambos lados.
* **Calibración del Ángulo Central:** Ajuste gradualmente el valor del ángulo hasta que las ruedas apunten perfectamente en línea recta con respecto al chasis.
* **Prueba de Límites Seguros:** Incremente y decremente el ángulo progresivamente hacia la izquierda y hacia la derecha. Detenga la prueba inmediatamente si detecta resistencia mecánica o esfuerzo en el brazo de dirección, registrando los límites máximos alcanzados.

---

### **Criterios de Finalización**

* **Validación:** El mecanismo de dirección debe moverse de manera fluida en todo su recorrido sin atascos ni ruidos mecánicos. Al restaurar el ángulo central, las ruedas deben quedar completamente alineadas.
* **Guardado de Configuración:** Actualice la constante del centro mecánico en el script principal y asegúrese de que los algoritmos de navegación restrinjan los ángulos de salida estrictamente dentro de los límites seguros probados.

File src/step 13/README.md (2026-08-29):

## Step 13

### Resumen

El paso 13 evalúa la capacidad de esquivar un único obstáculo a una velocidad controlada de 600 pasos/s en cuatro condiciones distintas: ambas direcciones de conducción (derecha e izquierda) combinadas con ambos colores de obstáculo (verde y rojo). La prueba utiliza la lógica de competición existente, el proceso de procesamiento de la cámara y los modelos de seguimiento de paredes sin necesidad de realizar modificaciones en `main.py` ni en el firmware de Arduino.

___

### Reglas y Sistema

* **Reglas sobre obstáculos:**
* **Obstáculos verdes:** El robot debe pasar por el lado **derecho**.
* **Obstáculos rojos:** El robot debe pasar por el lado **izquierdo**.
* *Nota:* El indicador `--direction` indica la dirección de la vuelta, no el lado por el que debe esquivar el obstáculo.

* **Comprobación previa al vuelo:** Antes de moverse, el software comprueba que el color del obstáculo objetivo sea visible. Si no se detecta, el sistema se detiene (`PREFLIGHT_OBSTACLE_NOT_CONFIRMED`).
* **Límites calibrados:**
* Centro del servo: 82
* Límites del servo en dirección izquierda: 75–92
* Límites del servo en dirección derecha: 72–90

___

### Instrucciones

1. **Script de configuración y directorios**
* Crea las carpetas de destino y el archivo del script de prueba directamente en la Raspberry Pi:
```bash
cd /home/admin/Projects/WRO2026-CLM/code/XX_2025_package
source ../.venv/bin/activate
mkdir -p step13_tests ../../step13_results/logs ../../step13_results/frames
touch step13_tests/__init__.py
nano step13_tests/obstacle_avoidance_low_speed.py

```

* Pega el contenido del script, guarda el archivo y comprueba que se compila correctamente con el comando `python -m py_compile step13_tests/obstacle_avoidance_low_speed.py`.

2. **Preparación del campo**
* Utiliza un único tramo recto de pista en el que solo se coloque el obstáculo de prueba en una posición reglamentaria.
* Coloca el robot en línea recta sobre la pista **entre 50 y 70 cm antes del obstáculo**.
* Asegúrate de que no haya cables sueltos, de que haya una línea de visión despejada para la comprobación previa al inicio y de que se pueda acceder manualmente al interruptor de encendido.

3. **Ejecuta las 4 configuraciones de prueba**
Ejecuta cada comando de forma secuencial, cambiando la posición del robot y los obstáculos entre cada ejecución:
* **Dirección derecha + obstáculo verde**
```bash
python -u -m step13_tests.obstacle_avoidance_low_speed --direction right --color green --steps 1700 2>&1 | tee ../../step13_results/logs/right_green_console.log

```

* **Dirección derecha + obstáculo rojo**
```bash
python -u -m step13_tests.obstacle_avoidance_low_speed --direction right --color red --steps 1700 2>&1 | tee ../../step13_results/logs/right_red_console.log

```

* **Dirección izquierda + obstáculo verde**
```bash
python -u -m step13_tests.obstacle_avoidance_low_speed --direction left --color green --steps 1700 2>&1 | tee ../../step13_results/logs/left_green_console.log

```

* **Dirección izquierda + obstáculo rojo**
```bash
python -u -m step13_tests.obstacle_avoidance_low_speed --direction left --color red --steps 1700 2>&1 | tee ../../step13_results/logs/left_red_console.log

```

___

### Troubleshooting

* **Distancia insuficiente:** Si la maniobra de evasión se ejecuta correctamente pero el robot se detiene antes de haber superado por completo el obstáculo, vuelve a ejecutar solo esa prueba concreta aumentando la distancia a `--steps 2000`. No aumentes la velocidad.
* **Interrupciones:** Pulsa `Ctrl+C` o apaga el interruptor de alimentación del motor si el robot intenta pasar por el lado equivocado, entra en contacto con una pared u obstáculo, u oscila excesivamente.

___

### Requisitos para superar la prueba (las 4 ejecuciones):

* Superada la comprobación previa (`Preflight passed: True`).
* El robot pasa por el verde a la derecha y por el rojo a la izquierda.
* Cero contacto con obstáculos o paredes, sin oscilaciones graves en la dirección y reanudación satisfactoria del seguimiento de la pared.
* Las salidas de los servos se mantienen dentro de los límites calibrados.
* El resumen de la consola muestra `Motivo de la parada: TARGET_COMPLETE` y `Resultado técnico: APROBADO`.

### Materiales que se deben enviar:

1. Empaquetar todos los resultados en un archivo:
```bash
cd /home/admin/Projects/WRO2026-CLM
tar -czf step13_for_review.tar.gz step13_results

```

2. Envía `step13_for_review.tar.gz` junto con las respuestas de observación de las cuatro ejecuciones (confirmando: lado correcto, sin contacto con obstáculos, sin contacto con paredes, sin oscilaciones fuertes).

___

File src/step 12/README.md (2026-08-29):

## Step 12

### Resumen

El paso 12 pone a prueba la capacidad del robot para completar una vuelta completa sin obstáculos a una velocidad fija de 600 pasos/s. Utilizando el firmware de competición existente del paso 11 junto con las clases del repositorio principal (`CameraManager`, `LapTracker`, `ContextManager` y `ArduinoComms`), el robot sigue y recorre cuatro cuartos de vuelta mediante la detección de líneas azules y naranjas, deteniéndose automáticamente una vez completada la vuelta.

___

### Instrucciones

1. **Preparación del campo**
* Retira todos los obstáculos rojos y verdes, así como los elementos de aparcamiento, de la pista.
* Mantén una iluminación constante (que se ajuste a las condiciones del paso 11).
* Coloca el robot centrado en un tramo recto antes de la primera secuencia de líneas azules y naranjas, asegurándote de que los cables USB queden sueltos.

2. **Configuración y verificación del script**
* Instala `step12_one_complete_lap.py` en la Raspberry Pi:
```bash
cd /home/admin/Projects/WRO2026-CLM/code/XX_2025_package
source ../.venv/bin/activate
mkdir -p step12_tests ../../step12_results/logs ../../step12_results/frames
touch step12_tests/__init__.py
cp ~/Descargas/step12_one_complete_lap.py step12_tests/one_complete_lap.py
```
* Comprueba que el script se compila correctamente y que se importan los módulos:
```bash
python -m py_compile step12_tests/one_complete_lap.py
```
* Asegúrate de que la conexión con Arduino se reconoce en `/dev/ttyACM0`.

3. **Ejecución**
* Ejecuta la prueba en cualquiera de las dos direcciones (solo es necesaria una):
* **Dirección derecha:**
```bash
python -u -m step12_tests.one_complete_lap --direction right 2>&1 | tee ../../step12_results/logs/right_console.log
```
* **Dirección izquierda:**
```bash
python -u -m step12_tests.one_complete_lap --direction left 2>&1 | tee ../../step12_results/logs/left_console.log

```
* Despeja el circuito durante la cuenta atrás de 5 segundos.

4. **Seguimiento y parada automática**
* La parada se activa cuando el `LapTracker` registra cuatro cuartos de vuelta consecutivos (del `1/4` al `4/4`).
* Los límites de la dirección servo se aplican dinámicamente en función de la dirección (derecha: 72–90; izquierda: 75–90).
* Los límites de seguridad de respaldo (25 000 pasos / tiempo de espera de 50 segundos) solo existen para interrupciones de emergencia.

___

### Seguridad y resolución de problemas

* **Interrupción de emergencia:** Pulsa inmediatamente `Ctrl+C` o acciona el interruptor de encendido del motor si el robot corre el riesgo de chocar contra una pared, se salta un giro, oscila violentamente, no se detiene o si la cámara se bloquea.
* **Problemas de detección de la línea:** No aumentes los límites de pasos ni los tiempos de espera si la vuelta física se completa sin alcanzar «4/4»; esto indica un problema de detección de la línea, no una limitación de distancia.

___

### Requisitos para superar la prueba:

* Los informes técnicos indican «Vuelta completada: True», «Motivo de la parada: LAP_COMPLETE» y «Resultado técnico: PASS».
* El robot recorre cuatro esquinas físicas sin chocar contra las paredes ni oscilar de forma severa.
* Se detiene automáticamente cerca de la sección de salida al registrar 4/4 cuartos de vuelta.

### Entregables que hay que presentar:

* Salida final del registro de la consola:
```bash
tail -n 25 ../../step12_results/logs/right_console.log
```
* El último archivo CSV de registro generado durante la ejecución.
* Cuatro confirmaciones de observación física:
1. Se ha completado una vuelta física (sí/no)
2. Contacto con la pared (sí/no)
3. Oscilación intensa (sí/no)
4. Se ha detenido automáticamente cerca de la sección de salida (sí/no)

*(Nota: Las imágenes de diagnóstico solo son necesarias si se produce un contacto con la pared o si la prueba da como resultado `REVIEW`).*

___

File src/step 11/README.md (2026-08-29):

## Step 11

### Resumen

En el paso 11 se comprueba la capacidad del robot para sortear una sola esquina a baja velocidad (600 pasos/s) utilizando el algoritmo de seguimiento de paredes y el sistema de visión de serie. Se evalúan tanto los giros a la izquierda como a la derecha utilizando el firmware de Arduino existente del paso 10, sin que sea necesario recalibrar el algoritmo ni los servomotores.

___

### Instrucciones

1. **Instalación y verificación del script**
* Descarga el archivo `step11_one_corner_low_speed.py` en la Raspberry Pi, en el directorio `/home/admin/Projects/WRO2026-CLM/code/XX_2025_package/step11_tests/one_corner_low_speed.py`.
* Crea las carpetas de salida: `step11_results/logs` y `step11_results/frames`.
* Compila el archivo Python con el comando `python -m py_compile` para verificar la sintaxis.
* Verifica las dependencias del paquete con:
```bash
python -c «from classes.camera_manager import CameraManager; from classes.image_algoriths import ImageAlgorithms; from classes.arduino_comms import ArduinoComms; print(“STEP 11 IMPORTS OK”)»

```

2. **Lógica de parada automática**
* El límite de recorrido por defecto está fijado en **6.500 pasos**.
* Al detectar una esquina, el objetivo se ajusta automáticamente a **4.000 pasos** tras el giro.
* Una carrera superada concluye con el motivo de parada: `CORNER_EXIT_COMPLETE`. Alcanzar el límite de reserva sin detectar una esquina (`MAX_DISTANCE_COMPLETE_NO_CORNER`) constituye una carrera fallida.

3. **Preparación del campo**
* Utiliza una sección del campo WRO libre de obstáculos con una recta de entre 400 y 500 mm que preceda a una curva despejada.
* Alinea el robot en paralelo a la pared de salida, asegurándote de que no haya interferencias con los cables.

4. **Ejecución en la esquina izquierda**
* Coloca el robot en el carril de giro a la izquierda.
* Ejecuta el comando:
```bash
python -m step11_tests.one_corner_low_speed --direction left --max-steps 6500 --exit-steps 4000 2>&1 | tee ../../step11_results/logs/left_console.log

```
* Aléjate durante la cuenta atrás de 5 segundos.
* Comprueba que el robot sigue la pared (rango del servo: 75–90), detecta la esquina, completa el giro, entra en la siguiente recta y se detiene sin tocar la pared ni presentar oscilaciones excesivas en la dirección.

5. **Ejecución en la esquina derecha**
* Mueve el robot para que se acerque a la esquina desde la dirección opuesta.
* Ejecuta el comando:
```bash
python -m step11_tests.one_corner_low_speed --direction right --max-steps 6500 --exit-steps 4000 2>&1 | tee ../../step11_results/logs/right_console.log
```
* Comprueba que el rendimiento del giro sea idéntico en dirección hacia la derecha.

___

### Ajustes de seguridad y distancia

* **Interrupción de emergencia:** Pulsa `Ctrl+C` o utiliza el interruptor físico de encendido si el robot gira incorrectamente, oscila violentamente, se mueve hacia atrás o corre el riesgo de chocar contra una pared.
* **Ajuste de los pasos de salida:** Si es necesario ajustar la posición de parada física tras una pasada técnica:
* *Se queda corto en la curva:* Aumenta a `--exit-steps 4500`
* *Se pasa de largo en la recta:* Disminuye a `--exit-steps 3500`

___

### Requisitos de la pasada (en ambas direcciones):

* Estado técnico: `PASS` (`Curva aceptada: True`, `Objetivo completado: True`, `Motivo de la parada: CORNER_EXIT_COMPLETE`).
* Velocidad fija en 600; salida del servo entre 75 y 90.
* Giro de ~90° completado hacia la siguiente recta.
* Sin choques contra las paredes, oscilaciones continuas de la dirección ni movimiento hacia atrás.

### Materiales que se deben presentar:

* Archivos de registro: `left_console.log` y `right_console.log`.
* Archivos CSV de telemetría de ambas pruebas.
* 6 imágenes de diagnóstico (3 por prueba: aproximación a la recta, fotograma `_CORNER` y salida de la recta).
* Notas de observación de ambas pruebas en las que se evalúen la finalización de la curva, el contacto con la pared, la alineación en la salida y la gravedad de la oscilación.

___

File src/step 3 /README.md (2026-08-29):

## Step 3

### Resumen

El objetivo de este paso es comprobar que el Arduino Uno puede ejecutar correctamente el firmware del proyecto y que la Raspberry Pi 5 lo reconoce como un dispositivo serie USB.

Antes de probar la comunicación con el Arduino a través del programa de Python, es necesario que el firmware del Arduino se compile y se cargue correctamente. El proyecto de Arduino se gestiona por separado del paquete de Python y contiene varios archivos fuente y de cabecera necesarios para la compilación. El firmware utiliza la clase `SerialReceiver` para procesar los comandos entrantes e inicializa la comunicación serie a `115200` baudios.

Tras cargar el firmware, el Arduino se conecta a la Raspberry Pi a través de USB. A continuación, se comprueba en la Raspberry Pi la presencia del dispositivo serie utilizado por el sistema de comunicación en Python del proyecto. La configuración actual del proyecto espera que el Arduino aparezca como `/dev/ttyACM0`.

El procedimiento consiste en:

1. Localizar el código fuente del proyecto de Arduino y comprobar que la estructura completa del proyecto está disponible.
2. Conectar el Arduino Uno a un ordenador mediante un cable de datos USB.
3. Abrir el proyecto de Arduino en el IDE de Arduino.
4. Seleccionar la placa Arduino Uno y el puerto serie correcto.
5. Compilar el proyecto de Arduino y confirmar que no se producen errores.
6. Cargar el firmware en el Arduino y confirmar que la carga se realiza correctamente.
7. Conectar el Arduino a la Raspberry Pi 5 a través de USB.
8. Comprobar si la Raspberry Pi detecta el Arduino como un dispositivo serie `ttyACM`.
9. Confirmar que `/dev/ttyACM0` está disponible.
10. Solucionar los problemas de conexión USB o de asignación del dispositivo serie si no se detecta el dispositivo esperado.

Objetivo:
Confirmar que el firmware de Arduino se compila y se carga correctamente, y que la Raspberry Pi puede detectar el Arduino como el dispositivo serie USB `/dev/ttyACM0` requerido por el sistema de comunicación en Python del proyecto.

El paso 3 se da por completado cuando:
* La estructura completa del proyecto de Arduino está disponible.
* El proyecto de Arduino se compila correctamente sin errores.
* El firmware se carga correctamente en el Arduino Uno.
* El Arduino está conectado a la Raspberry Pi 5 a través de una conexión de datos USB.
* La Raspberry Pi detecta el Arduino como un dispositivo serie.
* `/dev/ttyACM0` está disponible y el sistema puede acceder a él.
* No se producen desconexiones USB repetidas ni errores de conexión.

___

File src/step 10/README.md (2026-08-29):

## Step 10

### Resumen

El paso 10 valida el algoritmo de seguimiento de paredes de la competición en un entorno de línea recta y a baja velocidad antes de intentar realizar giros. Integra el firmware original de Arduino, los módulos `CameraManager`, `ImageAlgorithms` y `ArduinoComms` del repositorio para garantizar que el control de dirección en bucle cerrado funcione correctamente sin chocar contra las paredes ni oscilar.
___

### Preparación y configuración

1. **Restauración del firmware:** Vuelve a flashear el firmware original de la competición a través de PlatformIO (`code/arduino`) para restaurar los protocolos estándar de comunicación serie:
* Comando de movimiento continuo: `m<ángulo>,<velocidad>.`
* Comando de movimiento por pasos hasta un objetivo: `<pasos>!`

2. **Configuración del entorno y los directorios:** Configura el entorno virtual de Python y las dependencias, y crea los directorios `step10_results/logs` y `step10_results/frames`.

3. **Reasignación de ángulos:** Asigna el ángulo central predeterminado del repositorio (86) al centro físico calibrado del robot (**82**), limitando los límites de giro operativos entre **75 (derecha)** y **90 (izquierda)**.

___

### Ejecución

**Creación del script:** Implementa `step10_tests/wall_follow_low_speed.py`, que:
* Acepta `--direction` (`left` o `right`), `--steps` (100–2000) y `--speed` (fijada en 600 pasos/segundo).
* Realiza una cuenta atrás de 5 segundos.
* Captura imágenes de forma continua, calcula las posiciones de las paredes mediante `find_wall_to_follow()`, convierte dinámicamente los ángulos de giro y actualiza el Arduino.
* Registra la telemetría de la ejecución en un archivo CSV y guarda fotogramas de diagnóstico cada 5 fotogramas.

**Progresión de las pruebas:**
1. **Prueba con rueda levantada:** Verifica los movimientos de los servos, los límites (75–90) y el apagado automático del motor (`TARGET_COMPLETE`) sin contacto con el suelo.
2. **Recorridos cortos por el suelo:** Ejecuta 500 pasos (~300 mm) tanto hacia la izquierda como hacia la derecha en una trayectoria recta.
3. **Recorridos medios por el suelo:** Ejecutar 1000 pasos (~600 mm).
4. **Recorridos completos de 1 metro:** Ejecutar 1660 pasos (~1000 mm) tanto hacia la izquierda como hacia la derecha.

___

### Criterios de finalización 

**Criterios de superación:**
* Ejecución impecable utilizando componentes reales del repositorio (`CameraManager`, `ArduinoComms` y `calculate_servo_angle_from_walls()`).
* Finalización satisfactoria de recorridos de 1660 pasos (~1 metro) en ambas direcciones a una velocidad de 600.
* Cero contactos con las paredes, cero oscilaciones excesivas de la dirección y parada automática a la distancia objetivo.

**Resultados que deben incluirse en el informe:**
* Salidas de la consola de las pruebas de 1 660 pasos hacia la izquierda y hacia la derecha.
* Archivos de registro (`.csv`) de `step10_results/logs/`.
* Imágenes de diagnóstico (`.jpg`) de `step10_results/frames/`.
* Informe de estado que confirme la ausencia de contacto con las paredes y de oscilaciones en ambas pruebas.

____

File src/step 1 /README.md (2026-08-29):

## Step 1

### Resumen

El objetivo de este paso es comprobar que la Raspberry Pi 5 detecta correctamente el módulo de cámara «Camera Module 3 Wide» y se comunica con él antes de continuar con cualquier código específico del proyecto relacionado con la cámara o el procesamiento de imágenes.

Se trata de un paso de validación a nivel de hardware y del sistema. La cámara debe estar primero conectada físicamente de forma correcta y ser reconocida por el sistema operativo Raspberry Pi antes de que pueda ser utilizada por los sistemas Python Picamera2, OpenCV y de procesamiento de imágenes del proyecto.

El procedimiento consiste en:

1. Apagar de forma segura la Raspberry Pi antes de conectar o volver a conectar la cámara.
2. Comprobar la conexión física del cable plano CSI.
3. Arrancar la Raspberry Pi.
4. Verificar que la cámara se detecta mediante el comando rpicam-hello --list-cameras.
5. Confirmar que la cámara puede inicializarse y mostrar una vista previa en directo mediante rpicam-hello.

Objetivo:
Confirmar que la Raspberry Pi 5 puede detectar e inicializar correctamente el módulo de cámara 3 Wide.

El paso 1 se da por completado cuando:
rpicam-hello --list-cameras detecta al menos una cámara.
rpicam-hello inicializa correctamente la cámara y muestra una vista previa en directo.

____

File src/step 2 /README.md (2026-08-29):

## Step 2

### Resumen

El objetivo de este paso es comprobar que el entorno de Python de la Raspberry Pi puede acceder correctamente a las bibliotecas externas y a los módulos internos del proyecto que requiere el software del robot.

Antes de probar la captura de la cámara, el procesamiento de imágenes, la comunicación con Arduino o el programa autónomo completo, las dependencias de Python necesarias para el proyecto deben estar disponibles e importarse correctamente. Esto incluye bibliotecas externas como `cv2`, `numpy`, `serial` y `Picamera2`, así como módulos internos del proyecto dentro de los directorios `classes/` y `utils/`.

El procedimiento consiste en:

1. Acceder al directorio del proyecto de Python.
2. Confirmar que Python 3 está disponible e identificar el ejecutable de Python que se está utilizando.
3. Probar las bibliotecas externas básicas del proyecto.
4. Verificar que se pueda importar la biblioteca de la cámara `Picamera2`.
5. Probar las importaciones relacionadas con la cámara del proyecto a través de `CameraManager`.
6. Probar el conjunto completo de importaciones que requiere el programa principal sin poner en marcha el robot.

Objetivo:
Confirmar que el entorno de Python puede importar correctamente las bibliotecas externas y los módulos internos del proyecto que requiere el software del robot.

El paso 2 se da por completado cuando:
* Python 3 está disponible y se ejecuta correctamente.
* Se importan correctamente `cv2`, `numpy` y `serial`.
* Se importa correctamente `Picamera2`.
* Se importa correctamente `CameraManager`.
* Se importan correctamente los módulos necesarios del proyecto principal.
* No se producen errores `ModuleNotFoundError`, `ImportError` ni otros errores relacionados con la importación.

**Note:** Este paso solo verifica que se puedan importar las dependencias de software necesarias y los módulos del proyecto. No comprueba la captura de la cámara, el procesamiento de imágenes, la comunicación con Arduino ni la ejecución del programa autónomo completo.

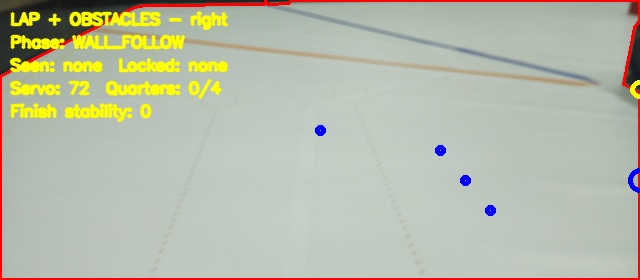
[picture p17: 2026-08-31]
step13_lap_results/frames/right_20260828_172251/frame_0008_WALL_FOLLOW.jpg

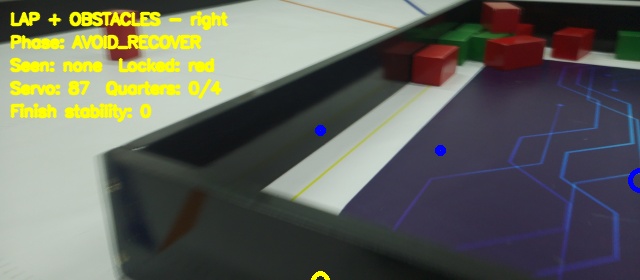
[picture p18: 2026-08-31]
step13_lap_results/frames/right_20260828_172724/frame_0048_AVOID_RECOVER.jpg

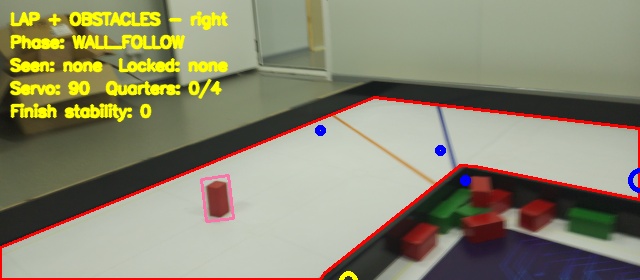
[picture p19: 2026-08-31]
step13_lap_results/frames/right_20260828_172251/frame_0064_WALL_FOLLOW.jpg

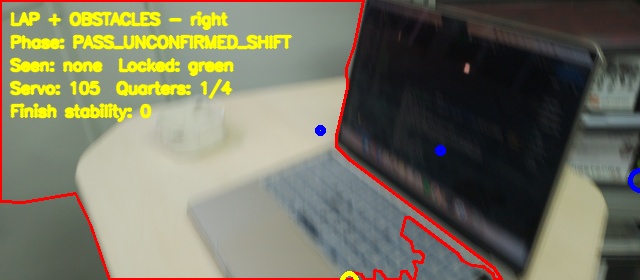
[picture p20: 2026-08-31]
step13_lap_results/frames/right_20260828_172251/frame_0112_PASS_UNCONFIRMED_SHIFT.jpg

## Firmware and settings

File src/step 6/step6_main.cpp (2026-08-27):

#include <Arduino.h>
#include <FlexyStepper.h>
#include <Servo.h>

// Existing robot wiring
constexpr uint8_t ENABLE_PIN = 2;
constexpr uint8_t STEP_PIN = 9;
constexpr uint8_t DIR_PIN = 10;
constexpr uint8_t SERVO_PIN = 11;

// Results from Step 4
constexpr int SERVO_MIN = 74;
constexpr int SERVO_CENTER = 99;
constexpr int SERVO_MAX = 124;

// Results from Step 5
constexpr float TEST_SPEED = 600.0F;
constexpr float ACCELERATION = 2000.0F;

// Initial estimate for approximately 1000 mm
constexpr long TEST_STEPS = 6400L;

// Repository direction: negative step position is forward.
// Change this to +1 only if the robot moves backward.
constexpr int FORWARD_SIGN = -1;

// Time to move away after entering GO
constexpr unsigned long START_DELAY_MS = 5000UL;

Servo steeringServo;
FlexyStepper stepper;

enum RunState {
    IDLE,
    COUNTDOWN,
    MOVING,
    STOPPING
};

RunState state = IDLE;

String serialCommand;
unsigned long countdownStarted = 0;
int selectedCenter = SERVO_CENTER;

void printHelp()
{
    Serial.println();
    Serial.println(F("=== STEP 6 STRAIGHT-LINE TEST ==="));
    Serial.println(F("Commands:"));
    Serial.println(F("  GO      - wait 5 seconds, then run"));
    Serial.println(F("  STOP    - cancel or decelerate to stop"));
    Serial.println(F("  A98     - set steering angle to 98"));
    Serial.println(F("  A99     - restore steering angle to 99"));
    Serial.println(F("  STATUS  - show current settings"));
    Serial.println(F("  HELP    - show these instructions"));
    Serial.println();
}

void printStatus()
{
    Serial.println(F("----- STATUS -----"));

    Serial.print(F("Steering angle: "));
    Serial.println(selectedCenter);

    Serial.print(F("Target steps: "));
    Serial.println(TEST_STEPS);

    Serial.print(F("Speed: "));
    Serial.println(TEST_SPEED);

    Serial.print(F("Acceleration: "));
    Serial.println(ACCELERATION);

    Serial.print(F("Motor position: "));
    Serial.println(stepper.getCurrentPositionInSteps());

    Serial.print(F("State: "));

    switch (state) {
        case IDLE:
            Serial.println(F("IDLE"));
            break;

        case COUNTDOWN:
            Serial.println(F("COUNTDOWN"));
            break;

        case MOVING:
            Serial.println(F("MOVING"));
            break;

        case STOPPING:
            Serial.println(F("STOPPING"));
            break;
    }
}

void scheduleRun()
{
    if (state != IDLE) {
        Serial.println(F("Run rejected: robot is not idle."));
        return;
    }

    steeringServo.write(selectedCenter);

    // Keep the driver disabled during the countdown.
    digitalWrite(ENABLE_PIN, HIGH);

    countdownStarted = millis();
    state = COUNTDOWN;

    Serial.println();
    Serial.println(F("GO accepted."));
    Serial.println(F("Robot will move in 5 seconds."));
    Serial.println(F("Clear the path and keep the USB cable loose."));
}

void beginMovement()
{
    stepper.setCurrentPositionInSteps(0);
    stepper.setTargetPositionInSteps(0);
    stepper.setSpeedInStepsPerSecond(TEST_SPEED);
    stepper.setAccelerationInStepsPerSecondPerSecond(ACCELERATION);

    digitalWrite(ENABLE_PIN, LOW);

    stepper.setTargetPositionRelativeInSteps(
        FORWARD_SIGN * TEST_STEPS
    );

    state = MOVING;

    Serial.println(F("MOVING"));
}

void requestStop()
{
    if (state == IDLE) {
        Serial.println(F("Robot is already stopped."));
        return;
    }

    if (state == COUNTDOWN) {
        state = IDLE;
        digitalWrite(ENABLE_PIN, HIGH);
        Serial.println(F("Countdown cancelled."));
        return;
    }

    stepper.setTargetPositionToStop();
    state = STOPPING;

    Serial.println(F("STOP requested: decelerating."));
}

void setSteeringAngle(const int newAngle)
{
    if (state != IDLE) {
        Serial.println(F("Stop the robot before changing the angle."));
        return;
    }

    if (newAngle < SERVO_MIN || newAngle > SERVO_MAX) {
        Serial.print(F("Invalid angle. Allowed range: "));
        Serial.print(SERVO_MIN);
        Serial.print(F(" to "));
        Serial.println(SERVO_MAX);
        return;
    }

    selectedCenter = newAngle;
    steeringServo.write(selectedCenter);

    Serial.print(F("Steering angle set to: "));
    Serial.println(selectedCenter);
}

void processCommand(String command)
{
    command.trim();
    command.toUpperCase();

    if (command.length() == 0) {
        return;
    }

    if (command == "GO") {
        scheduleRun();
    }
    else if (command == "STOP") {
        requestStop();
    }
    else if (command == "STATUS") {
        printStatus();
    }
    else if (command == "HELP") {
        printHelp();
    }
    else if (command.startsWith("A")) {
        const int requestedAngle = command.substring(1).toInt();
        setSteeringAngle(requestedAngle);
    }
    else {
        Serial.print(F("Unknown command: "));
        Serial.println(command);
        Serial.println(F("Enter HELP for the command list."));
    }
}

void readSerial()
{
    while (Serial.available() > 0) {
        const char received = static_cast<char>(Serial.read());

        if (received == '\r') {
            continue;
        }

        if (received == '\n') {
            processCommand(serialCommand);
            serialCommand = "";
        }
        else if (serialCommand.length() < 30) {
            serialCommand += received;
        }
    }
}

void setup()
{
    Serial.begin(115200);

    pinMode(ENABLE_PIN, OUTPUT);

    // DRV8825 ENABLE is active-low.
    digitalWrite(ENABLE_PIN, HIGH);

    steeringServo.attach(SERVO_PIN);
    steeringServo.write(SERVO_CENTER);

    stepper.connectToPins(STEP_PIN, DIR_PIN);
    stepper.setCurrentPositionInSteps(0);
    stepper.setTargetPositionInSteps(0);
    stepper.setSpeedInStepsPerSecond(TEST_SPEED);
    stepper.setAccelerationInStepsPerSecondPerSecond(ACCELERATION);

    delay(700);

    printHelp();
    printStatus();
}

void loop()
{
    readSerial();

    if (
        state == COUNTDOWN &&
        millis() - countdownStarted >= START_DELAY_MS
    ) {
        beginMovement();
    }

    if (state == MOVING || state == STOPPING) {
        stepper.processMovement();

        if (stepper.motionComplete()) {
            digitalWrite(ENABLE_PIN, HIGH);
            state = IDLE;

            Serial.println();
            Serial.println(F("DONE"));
            Serial.print(F("Final motor position: "));
            Serial.println(stepper.getCurrentPositionInSteps());
            Serial.println(F("Driver disabled."));
        }
    }
}

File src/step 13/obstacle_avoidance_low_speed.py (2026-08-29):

from __future__ import annotations

import argparse
import csv
import time
from datetime import datetime
from pathlib import Path

import cv2

from classes.arduino_comms import ArduinoComms
from classes.camera_manager import CameraManager
from classes.context_manager import ContextManager
from classes.image_algoriths import ImageAlgorithms
from utils.enums import Direction


SERVO_CENTER = 82
REPOSITORY_CENTER = 86
SPEED_LIMIT = 600
FORWARD_SIGN = -1

SERVO_LIMITS = {
    "left": (75, 92),
    "right": (72, 90),
}


def parse_args():
    parser = argparse.ArgumentParser(
        description="Step 13: bounded, low-speed, single-obstacle test"
    )
    parser.add_argument("--direction", choices=("left", "right"), required=True)
    parser.add_argument("--color", choices=("green", "red"), required=True)
    parser.add_argument("--steps", type=int, default=1700)
    parser.add_argument("--speed", type=int, default=SPEED_LIMIT)
    parser.add_argument("--port", default="/dev/ttyACM0")
    parser.add_argument("--countdown", type=int, default=5)
    parser.add_argument("--preflight-frames", type=int, default=20)
    parser.add_argument("--save-every", type=int, default=5)
    return parser.parse_args()


def physical_servo_angle(repository_angle, direction):
    if repository_angle is None:
        repository_angle = REPOSITORY_CENTER

    requested = round(
        SERVO_CENTER + float(repository_angle) - REPOSITORY_CENTER
    )
    minimum, maximum = SERVO_LIMITS[direction]
    return max(minimum, min(maximum, requested))


def detected_color(is_green, x_center, y_center):
    if is_green is None or x_center is None or y_center is None:
        return "none"
    return "green" if is_green else "red"


def add_diagnostics(image, expected, detected, servo, phase):
    if image is None:
        return

    lines = (
        f"STEP 13 - {phase}",
        f"Expected: {expected}",
        f"Detected: {detected}",
        f"Servo: {servo}",
    )

    for index, text in enumerate(lines):
        cv2.putText(
            image,
            text,
            (10, 25 + index * 24),
            cv2.FONT_HERSHEY_SIMPLEX,
            0.55,
            (0, 255, 255),
            2,
            cv2.LINE_AA,
        )


def save_frame(path, image):
    if image is None:
        return False
    return bool(cv2.imwrite(str(path), image))


def main():
    args = parse_args()

    if args.steps <= 0:
        raise SystemExit("--steps must be greater than zero")
    if args.speed <= 0 or args.speed > SPEED_LIMIT:
        raise SystemExit("For Step 13, --speed must be between 1 and 600")

    direction_enum = (
        Direction.LEFT if args.direction == "left" else Direction.RIGHT
    )

    project_root = Path(__file__).resolve().parents[3]
    results_root = project_root / "step13_results"
    logs_dir = results_root / "logs"
    frames_root = results_root / "frames"
    timestamp = datetime.now().strftime("%Y%m%d_%H%M%S")
    run_name = f"{args.direction}_{args.color}_{timestamp}"
    csv_path = logs_dir / f"{run_name}.csv"
    frames_dir = frames_root / run_name

    logs_dir.mkdir(parents=True, exist_ok=True)
    frames_dir.mkdir(parents=True, exist_ok=True)

    camera = None
    arduino = None
    rows = []
    completed_target = False
    preflight_passed = False
    expected_frames = 0
    wrong_color_frames = 0
    obstacle_control_frames = 0
    saved_images = 0
    servo_commands = []
    stop_reason = "NOT_STARTED"
    error_text = ""

    print("=== STEP 13: SINGLE-OBSTACLE AVOIDANCE ===")
    print(f"Direction: {args.direction}")
    print(f"Expected obstacle: {args.color}")
    print(f"Speed: {args.speed}")
    print(f"Target steps: {args.steps}")
    print(f"Servo center: {SERVO_CENTER}")
    print(
        "Servo limits: "
        f"{SERVO_LIMITS[args.direction][0]}-"
        f"{SERVO_LIMITS[args.direction][1]}"
    )
    print(f"CSV: {csv_path}")
    print(f"Frames: {frames_dir}")

    try:
        context = ContextManager()
        context.set_challenge(2)
        context.set_direction(direction_enum)

        camera = CameraManager()
        algorithms = ImageAlgorithms(context, camera)
        camera.start_camera()

        arduino = ArduinoComms(port=args.port)
        time.sleep(2)
        arduino.send("m", SERVO_CENTER, 0)

        print()
        print("Preflight: motor is stopped while the camera checks the obstacle.")

        correct_preflight = 0
        wrong_preflight = 0

        for index in range(args.preflight_frames):
            camera.capture_image()
            camera.transform_image()
            object_angle, is_green, x_center, y_center = (
                algorithms.find_obstacle_angle_and_draw_lines()
            )
            seen = detected_color(is_green, x_center, y_center)
            raw_obstacle = algorithms.calculate_servo_angle_from_obstacle(
                object_angle, is_green
            )
            servo = physical_servo_angle(raw_obstacle, args.direction)

            if seen == args.color:
                correct_preflight += 1
            elif seen != "none":
                wrong_preflight += 1

            add_diagnostics(
                camera.display_image,
                args.color,
                seen,
                servo,
                "PREFLIGHT",
            )

            if index % 5 == 0 or seen != "none":
                if save_frame(
                    frames_dir / f"preflight_{index:03d}.jpg",
                    camera.display_image,
                ):
                    saved_images += 1

            time.sleep(0.04)

        preflight_passed = (
            correct_preflight >= 3
            and correct_preflight > wrong_preflight
        )

        print(
            "Preflight detections: "
            f"expected={correct_preflight}, other-color={wrong_preflight}"
        )

        if not preflight_passed:
            stop_reason = "PREFLIGHT_OBSTACLE_NOT_CONFIRMED"
            print("Motor will not start.")
            print(
                "Reposition the robot or obstacle so the expected color is "
                "clearly visible, then run the same command again."
            )
        else:
            print("Preflight passed. The expected obstacle is visible.")
            print("Keep one hand near Ctrl+C or the robot power switch.")

            for remaining in range(args.countdown, 0, -1):
                print(f"Starting in {remaining}...")
                time.sleep(1)

            if hasattr(arduino, "arduino"):
                arduino.arduino.reset_input_buffer()

            arduino.send("!", FORWARD_SIGN * args.steps)
            arduino.send("m", SERVO_CENTER, args.speed)

            start_time = time.monotonic()
            timeout = max(8.0, args.steps / args.speed + 6.0)
            frame = 0
            stop_reason = "RUNNING"

            while True:
                camera.capture_image()
                camera.transform_image()
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

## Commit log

2026-08-22 Rename Screenshot 2026-08-22 at 16.21.47.png to circuit_design
2026-08-22 Update README with new schematic details and components
2026-08-22 Add camera health check functionality
2026-08-22 Update and rename FINAL CODE to camera_health.py
2026-08-22 Convert prototype code to Python with camera integration
    Refactor prototype code from C++ to Python, integrating camera functionality and image processing.
2026-08-22 Update and rename Prototype Camera Code to capture.py
2026-08-22 Convert Arduino code to Python pipeline script
2026-08-24 Add files via upload
    Uploaded 3D-printed parts of the robot
    [BasePlaqueV4-modificadoV1.stl, BasePlaqueV4.STL, ButtonHolder.STL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]
2026-08-27 Rename base motor-grande-3D.stl to BaseMotorBig.stl
    [BaseMotorBig.stl]
2026-08-27 Add README for Step 7 steering geometry evaluation
    Added detailed README for Step 7, covering robot steering geometry evaluation, configuration, test methods, experimental data, and key takeaways.
2026-08-29 Enhance README with calibration setup and criteria
    Added detailed calibration instructions for steering alignment.
2026-08-29 Enhance README with motor testing procedures
    Added detailed instructions for motor direction verification, speed control via serial communication, and precise stop function based on distance without friction on the ground. Included preparation,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
2026-08-29 Add detailed design documentation for autonomous robot
    Document the design process and decisions for the autonomous robot, including modular chassis, transmission system, and camera support.
2026-08-29 Create Desarrollo de Software.md
